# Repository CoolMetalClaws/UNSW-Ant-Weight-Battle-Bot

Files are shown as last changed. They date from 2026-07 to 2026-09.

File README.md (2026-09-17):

# UNSW-Ant-Weight-Battle-Bot



This Project features a 150g Antweight battle Battle bot designed for a competition with a vertical 20,000 RPM spinner weapon. Haven't heard of combat robotics before? It's basically custom RC cars with weapons trying to destroy each other! This bot is my first Antweight bot ever! It features an agressive design with angular features, a powerful vertical rotary weapon, and wide front prongs to guide oponents to the pit! A melenki nano is used as the main control board with N20 motors as the main drive motors, and a BE1806 BLDC is the main weapon motor.

## Parts
### - Chassis
The main chassis of the bot with mounts for motors, the malenki nano, the ESC, the battery, and wiring.

### - Left and Right wheel Spike
Two spikes attached to the drive axels of both wheels, keeping the bot from getting stuck on the side and looking cool! They rotate along with the wheels.

### - Chassis Cover 
A lid for the bot to keep its guts inside when its getting beaten up and keep the LiPo from going boom

### - Front Floor Bumpers
To allow as much contact as possible with the floor when the bot is tilted slightly forwards. Printed separately to avoid supports and to make it easier to replace.

### - Weapon Struts
Previously a part of the chassis, the struts were seperated for easier assembly, easier replacement, and quicker prototyping. Another reason was to increase strength along the layer lines by printing the part flat.

### - Weapon Blade
A drum style asymetrical vertical weapon that has 2 teeth and a nasty bite

## Wiring Diagram



## BOM (Bill Of Materials)

| Component | Cost | Qty | Link |
|---|---|-----|---|
| Malenki Nano | $44.99 | 1x  | https://botbitz.com.au/collections/electronic-speed-controls/products/malenki-nano |
| | | | |
| Blue PETG CF | $22.99 | 1x  | https://siddament.com.au/collections/cf-wood-marble-petg/products/original-blue-petg-cf |
| | | | |
| 195mAh 2S LiPo Battery | $12 each ($50) | 5x  | https://llamaforge.com/product/195mah_2s_13g_lipo_battery/ |
| | | | |
| 34mm N20 Wheel | $1 each ($6) | 6x  | https://llamaforge.com/product/34mm-n20-wheel-4-6g/ |
| | | | |
| Screw Switch | $8 | 1x  | https://llamaforge.com/product/ant-screw-switch-mini-0-5g/ |
| | | | |
| BE1806 1400KV BLDC Motor | $19.80 | 1x  | https://llamaforge.com/product/be1806-motor-1400kv-25g/ |
| | | | |
| BLHELI-S 20A ESC | $15 | 1x  | https://llamaforge.com/product/blheli-s-20a-esc-1-7g/ |
| | | | |
| N20 Motor 1:10 | $8 each ($48)  | 6x  | https://llamaforge.com/product/n20-motor-110-9-7g/ |
| | | | |
| Jumper T16 Controller | $35 | 1x  | Second Hand (Will submit reimbursement report after purchase) |
| | | | |
| M3 Screws Assortment | $12.99 | 1x  | Purchased before to take measurements (Will submit reimbursement report after purchase) |

## Design Onshape Link
https://cad.onshape.com/documents/25a53636e7b7b41d942e0c22/w/8abc8a63af3d41352a374180/e/e18c3659cf4e695e54e4f741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

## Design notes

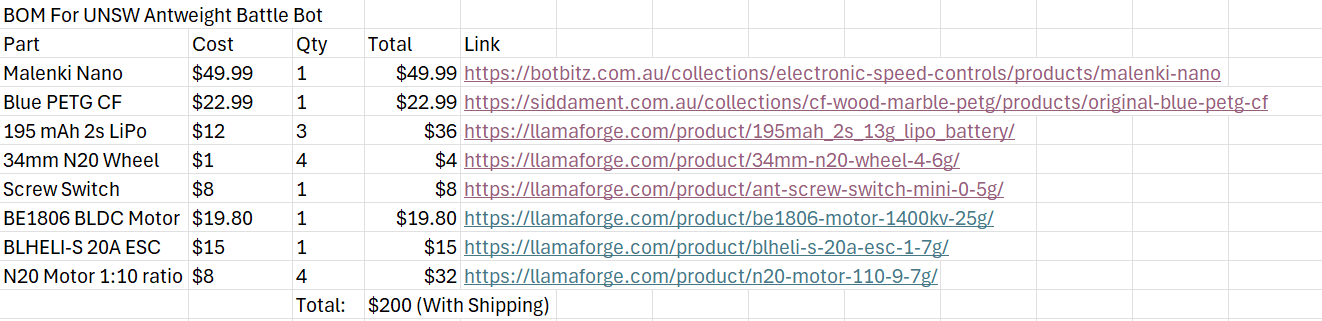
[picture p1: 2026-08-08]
Screenshot 2026-08-08 132551.png

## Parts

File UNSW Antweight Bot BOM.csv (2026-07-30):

BOM For UNSW Antweight Battle Bot
Part | Cost | Qty | Total | Link
Malenki Nano | $49.99 | 1 | $49.99 | https://botbitz.com.au/collections/electronic-speed-controls/products/malenki-nano
Blue PETG CF | $22.99 | 1 | $22.99 | https://siddament.com.au/collections/cf-wood-marble-petg/products/original-blue-petg-cf
195 mAh 2s LiPo | $12 | 3 | $36 | https://llamaforge.com/product/195mah_2s_13g_lipo_battery/
34mm N20 Wheel | $1 | 4 | $4 | https://llamaforge.com/product/34mm-n20-wheel-4-6g/
Screw Switch | $8 | 1 | $8 | https://llamaforge.com/product/ant-screw-switch-mini-0-5g/
BE1806 BLDC Motor | $19.80 | 1 | $19.80 | https://llamaforge.com/product/be1806-motor-1400kv-25g/
BLHELI-S 20A ESC | $15 | 1 | $15 | https://llamaforge.com/product/blheli-s-20a-esc-1-7g/
N20 Motor 1:10 ratio | $8 | 4 | $32 | https://llamaforge.com/product/n20-motor-110-9-7g/
 |  | Total: | $200 (With Shipping)

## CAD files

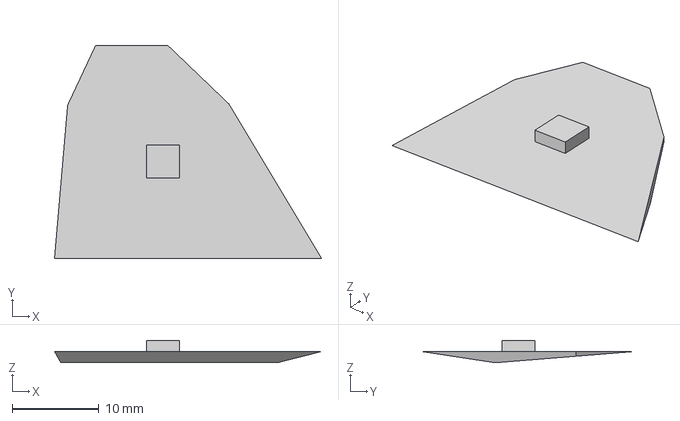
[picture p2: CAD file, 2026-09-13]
Cat-Aclysm MK3 - Chassis Front Floor Bumper Left.step
30.8 x 24.6 x 2.59 mm

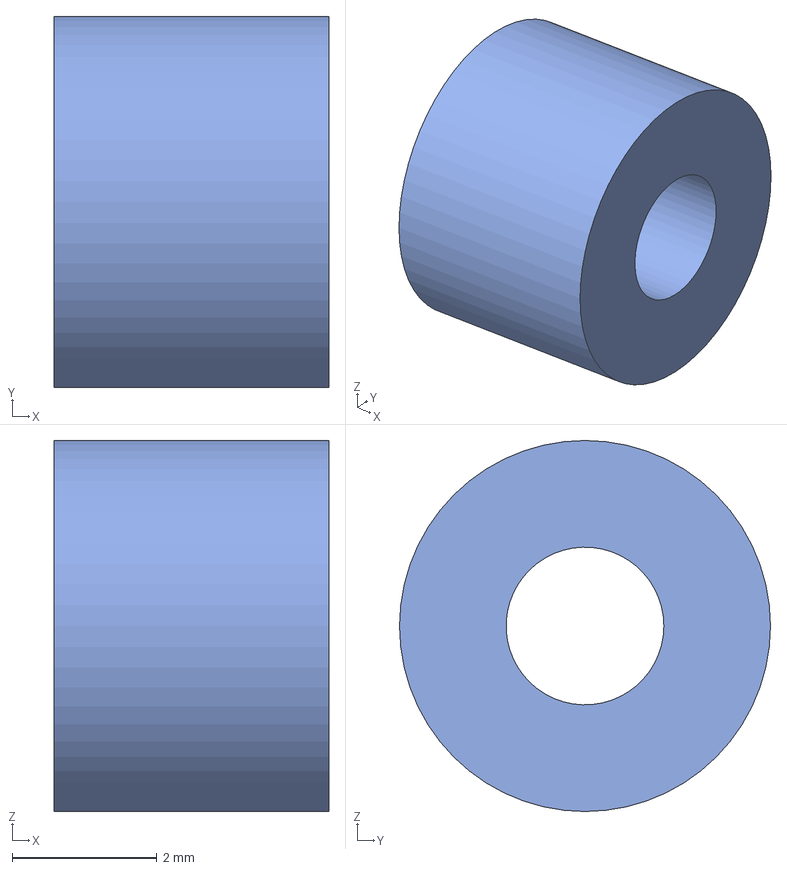
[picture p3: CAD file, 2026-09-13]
Cat-Aclysm MK3 - Bearing and Motor Spacer.step
3.80 x 5.13 x 5.13 mm

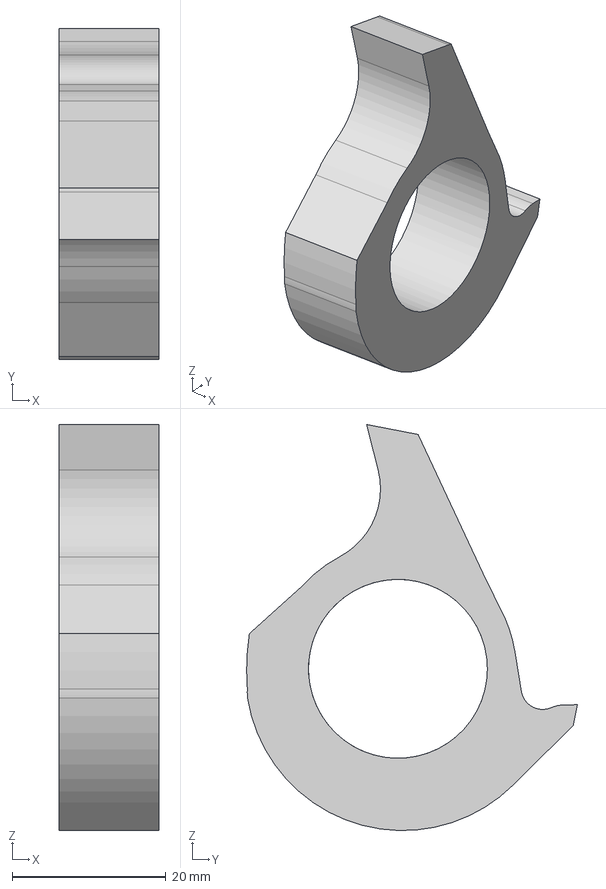
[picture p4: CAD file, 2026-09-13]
Cat-Aclysm MK3 - D.E.S Style Blade MK2 (Mineee).step
13.0 x 43.1 x 52.9 mm

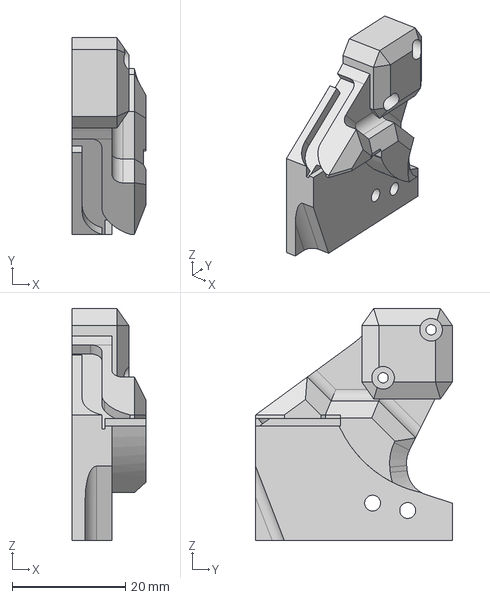
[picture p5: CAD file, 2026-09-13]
Cat-Aclysm MK3 - Left Weapon Strut.step
13.0 x 34.8 x 41.0 mm

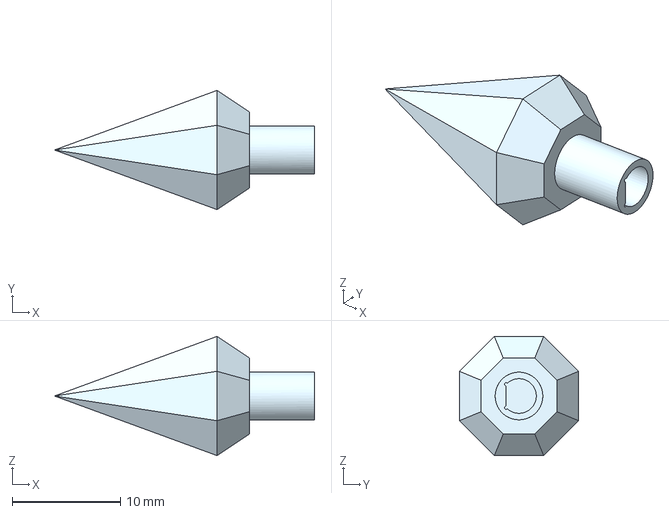
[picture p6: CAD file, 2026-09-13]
Cat-Aclysm MK3 - Right Wheel Spike.step
24.0 x 11.0 x 11.0 mm

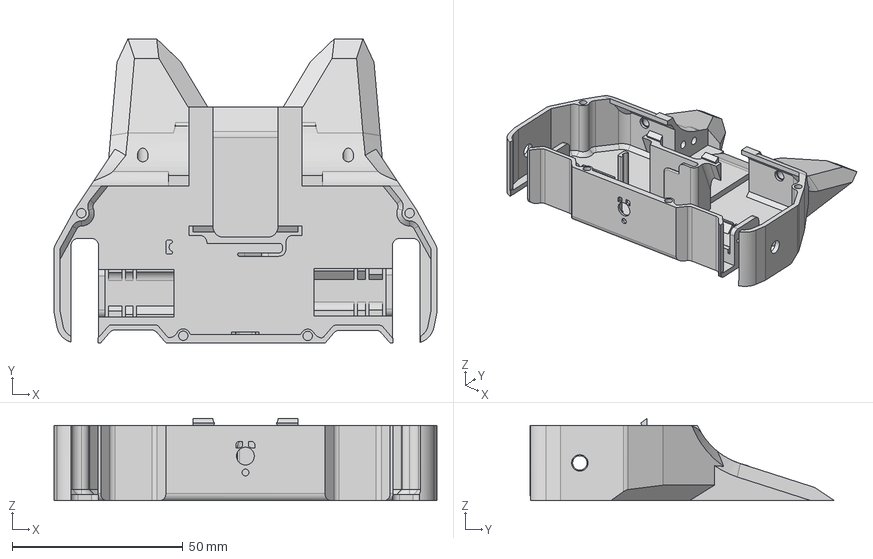
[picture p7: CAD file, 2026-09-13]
Cat-Aclysm MK3 - Chassis (Without Spikes).step
112.0 x 89.0 x 24.0 mm

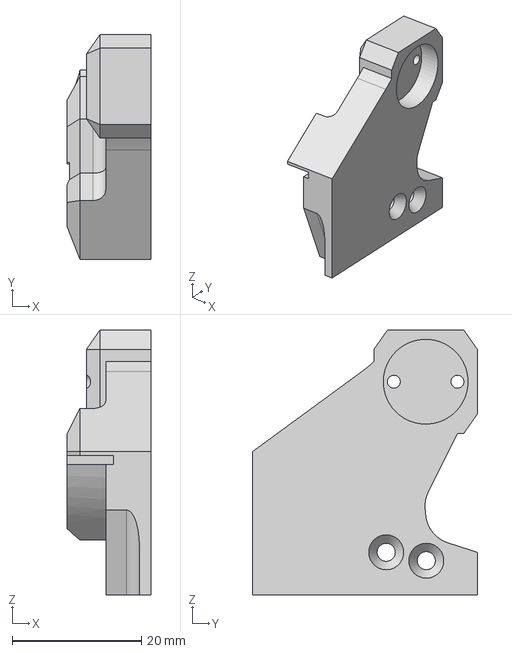
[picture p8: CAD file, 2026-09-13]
Cat-Aclysm MK3 - Right Weapon Strut.step
13.0 x 34.8 x 41.0 mm

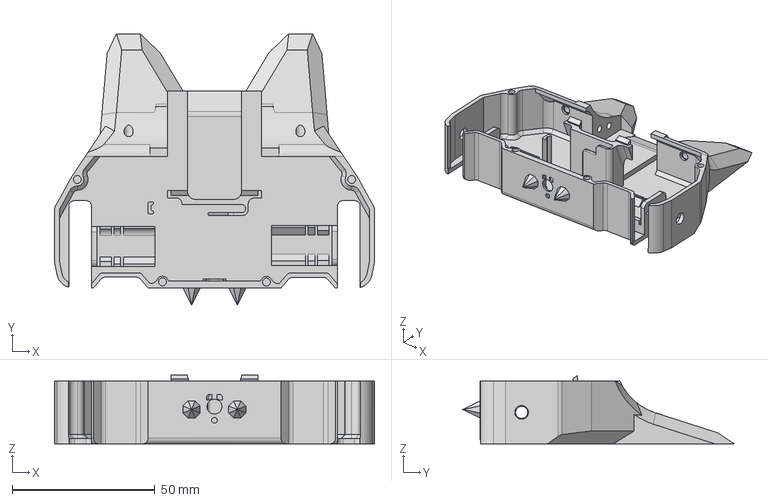
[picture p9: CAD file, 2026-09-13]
Cat-Aclysm MK3 - Chassis With Spikes.step
112.0 x 95.0 x 24.0 mm

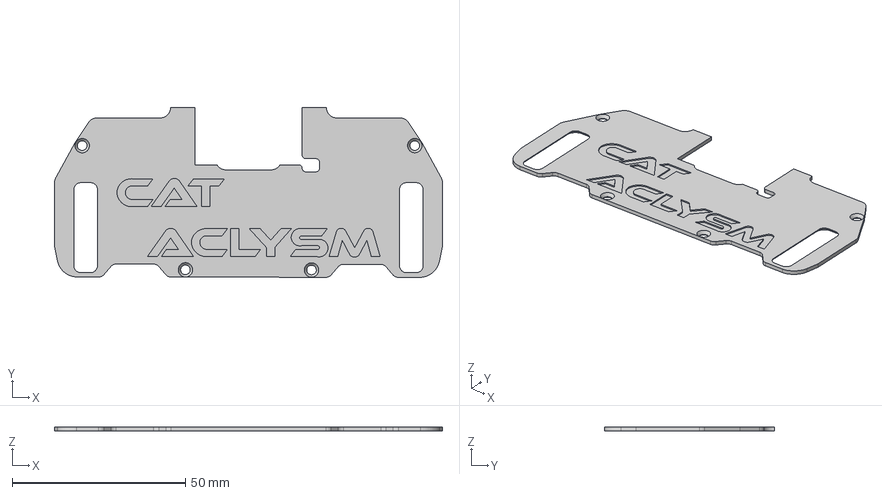
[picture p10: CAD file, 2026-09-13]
Cat-Aclysm MK3 - Chassis Cover.step
112.0 x 49.0 x 1.20 mm

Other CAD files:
Cat-Aclysm MK3 - Left Wheel Spike.step
Cat-Aclysm MK3 - Chassis Front Floor Bumper Right.step

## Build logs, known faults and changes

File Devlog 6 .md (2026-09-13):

# Final Tweaks

## Maths is over!
My maths test is finally done, so now i have some extra time to work on this! Sorry i havent posted a devlog in a while.

## 4hrs of tweaks
Im logging 4hrs of tweaking the design, making tiny changes to make it ready for printing with ABS! Some of the things i changed were;
 - Different type of N20 motor mounts
 - Added weapon motor mounts
 - Made the weapon struts removable and replaceable
 - Added routing for the weapon motor's wires
 - Added screw holes 

## DECIDED UPON A NAME!!!
This bot is officially registered into the competetion in 2 weeks as... drumroll.....Cat Aclysm! This name was chosen since the bot looks kinda like a cat from the top profile.

## Soldering
I began to solder together the parts of the bot, involving very intricate wire splicing because i thought it would be fun to add 2 LEDs instead of the required 1. :/ 

## Thats It!
Thats it for this devlog! Thank you for reading if you made it this far! 



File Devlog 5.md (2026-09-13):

# Partss!

## Funding Approved
Thank you soo much @RR for approving funding for my project! Sorry I haven’t posted a devlog in a while, I was ordering parts and doing the final tweaks to the design. All the parts have been ordered, and I’m currently waiting for delivery.

## Lower Chassis
I lowered the chassis by making the wheels closer to the floor, and sloped the front armour to restrict my bot from getting picked up from the front or outmanoeuvred. This also allows my bot to scoop up other bots and guide them into my weapon blade.

## Mouting the BE1806 motor
I split the chassis struts into seperate parts so they can be printed flat, which makes them stronger vertically. Then I added mounting holes for M2 screws, which directly screw into the motor. Then a channel was extruded to route the motor wires back through the chassis and to the ESC and the Malenki.

## Break
This project will be taking a back seat for the next week as I wait for parts to deliver and due to upcoming exams! I’ll finish the build pretty soon after though, as the event I’m competing in is on 20th September!

## Controller
I also purchased the controller for the bot, and will need to set it up myself soon! It is a Jumper T16 with replaced ribbons. An annoying thing is that i have to charge the batteries using a specific LiPo charger that I don’t have, so I’ll need to get that.

## Thank you!
Thanks for reading this devlog if u made it this far! Hope you’re as excited for this bot as I am! 

## P.S: I still need a name, so please suggest me some names in the comments below! Thank you!



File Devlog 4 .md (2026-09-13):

# Problems have arisen

## Switch Cover design

While I was waiting for the project to get approved for funding, I decided to add a small cover for the screw switch, and generally touch up the design. I countersunk the screw holes for M3 screws I bought (hopefully I can get re-imbursed for these as well) and designed 2 types of covers for the screw switch on the robot that turns it on. The two designs are attached in the image below, so please tell me which one I should keep on the bot! (Spikes or the flat, boring, plain cover)

## Weight Issues

My bot is slightly overweight, around 5 grams over, and I need to drop dead weight, especially from the chassis. I tried hollowing out the front prongs, but this actually increased the weight as it added more walls, meaning a denser design. I then adjusted some slicer settings and thinned the walls of my bot, which got the weight back under the limit. Unfortunately, I would prefer to have some margin as I still need to add hot glue to stick in the motors and the PCB, and my bot is currently 149.8 grams (the limit is 150g).

To solve this issue, I plan to make the blade thinner, which does mean it will have a lesser reach. If anyone has better suggestions to drop weight, pls let me know in the comments since I really would prefer to keep a wider blade.





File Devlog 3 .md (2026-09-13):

## Just a lil extra thing i was working on that i wanted to share!

Below is the image for my robot team's (just me so far) logo; Robo Sapiens! Lol I found this so amusing I had to make a devlog about it!



P.s if anyone has name suggestions for my bot, pls tell me, i currently have no idea what in going to name it

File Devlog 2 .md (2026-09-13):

## Chosen Design
After careful consideration, I chose the aggressive vertical front spinner as my final design. I have moderate to extensive experience in Onshape, so i used that to begin designing. Before beginning to design, i found STEP files for N20 motors and used the dimensions from my planning stage to place in the electronic components. Then i began with a roughly shaped sketch of the design, which i extruded to the desired length. Then I shelled it out with a 2mm wall to allow space for the electronics.



## Weapon design
My weapon blade design is based off James KIrby's D.E.S blade. The weapon support struts are extremely thick as many bots have lost their weapons due to broken struts. The weapon uses a BE1806 motor and a 20Ah ESC to drive it. The weapon unfortunately was not big enough to house the motor, so adjustments had to be made to allow a larger weapon.



## Feedback and Re-iteration
An extremely helpful individual from the university provided me extensive feedback upon the design, which significantly improved my design and allowed my robot to remain under the weight category. Thank you! 

### Specific Design modifications through feedback;
- Changed Malenki nano orientation to vertical just behind weapon
- Allowed the wheels to protrude slighly from the back so the bot doesnt get stuck on its back
- Smaller chassis for lesser weight (Removed unecessary space)
- Added Mounts for screw switch and LED

If you made it this far, thank you for reading! If you have any suggestions for my bot, I’m always willing to improve, so please tell me in the comments below. Thanks!

## Final Design is attached below along with a wiring diagram (It should be unless theres something else to fix)

### P.s there's a cover on the bot, i just dont have it visible in the renders







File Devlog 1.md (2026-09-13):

# Sketching Robot Designs and Parts with Dimensions 

## Inspiration 



I’ve always been intrigued by battle robots, and when I discovered that there is a competition near by that hosts mini battle bots, I was immediately drawn to it. I did lots of research into it and discovered there were many categories and classes. I decided to make a bot for the Antweight plastic class category, and one that would easily be upgraded to the open class category. An example battle bot is shown below (not mine).

## Overview

The Antweight Battle Bot competition is a miniature combat robotics event where custom-built remote-controlled machines face off in a bulletproof, enclosed arena. This weight class serves as the ultimate entry point for engineering hobbyists due to its low cost, minimal space requirements, and strict design constraints.

## Weapon and drive motor sketches with dimensions

I first sketched out the motors and electronic components used for the battle bot at a 1:1 scale with dimensions, to give me a better sense of the sizing of the parts and to start thinking of the arrangements.

## Bot concept sketches 

After planning a base robot in my mind, I finalised 3 main robot designs I liked. I sketched these 3 out and asked for input from a few people who have experience in this field, including Angus from makers muse (the YouTuber). I decided upon the vertical spinner design with aggressive front forks. My 3 bot sketches are attached below.

### Version 1: Viper


### Version 2: (Unamed)


### Version 3: Skull Krusher


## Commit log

2026-07-30 Enhance README with project details and BOM
    Added detailed parts list, wiring diagram, and BOM to README.
2026-07-30 Added BOM in .csv format
    [UNSW Antweight Bot BOM.csv]
2026-08-08 Enhance BOM section with links and images
    Updated BOM with product links and images.
2026-08-08 Revise BOM with new product details and images
    Updated BOM section with product links and images.
2026-08-08 BOM Screenshot
2026-08-11 Delete UNSW Antweight Battle Bot With Protruding back wheels - Chassis V2 STEP.step
    I need to upload new files (V3)
    [UNSW Antweight Battle Bot With Protruding back wheels - Chassis V2 STEP.step]
2026-08-11 Delete UNSW Antweight Battle Bot With Protruding back wheels - Chassis V2.stl
    I need to upload new V3 files
    [UNSW Antweight Battle Bot With Protruding back wheels - Chassis V2.stl]
2026-08-11 Delete UNSW Antweight Battle Bot With Protruding back wheels - Left Wheel Spike STEP.step
    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
    [UNSW Antweight Battle Bot With Protruding back wheels - Left Wheel Spike STEP.step]
2026-08-11 Delete UNSW Antweight Battle Bot With Protruding back wheels - Left Wheel Spike.stl
    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
    [UNSW Antweight Battle Bot With Protruding back wheels - Left Wheel Spike.stl]
2026-08-11 Delete UNSW Antweight Battle Bot With Protruding back wheels - Right Wheel Spike STEP.step
    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
    [UNSW Antweight Battle Bot With Protruding back wheels - Right Wheel Spike STEP.step]
2026-08-11 Delete UNSW Antweight Battle Bot With Protruding back wheels - Right Wheel Spike.stl
    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
    [UNSW Antweight Battle Bot With Protruding back wheels - Right Wheel Spike.stl]
2026-08-20 Refactor BOM section to table format
    Updated BOM section to use a table format for better readability and removed old list format.
2026-08-20 Enhance README with new components descriptions
    Added sections for Chassis Cover and Weapon Blade to the README.
2026-08-21 Add Jumper T16 Controller to BOM
    Added Jumper T16 Controller entry with pricing and notes.
2026-08-21 Change Malenki Nano cost from $49.99 to $44.99
    Updated the cost of Malenki Nano in the BOM section as it has been put on at a reduced price
2026-09-13 Add Devlog 5 with project updates and plans
    Documented recent project updates including funding approval, chassis modifications, motor mounting, and upcoming plans.
2026-09-13 Update Devlog 6 with recent progress and changes
    Added details about recent design tweaks, bot name, and soldering progress.
2026-09-13 Delete UNSW Antweight Battle Bot With Protruding back wheels MK2 - Chassis Cover.step
    Need to update files
    [UNSW Antweight Battle Bot With Protruding back wheels MK2 - Chassis Cover.step]
2026-09-13 Delete UNSW Antweight Battle Bot With Protruding back wheels MK2 - Chassis.step
    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
    [UNSW Antweight Battle Bot With Protruding back wheels MK2 - Chassis.step]
2026-09-13 Delete UNSW Antweight Battle Bot With Protruding back wheels MK2 - D.E.S Style Blade MK2 (Mineee) (1).step
    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
    [UNSW Antweight Battle Bot With Protruding back wheels MK2 - D.E.S Style Blade MK2 (Mineee) (1).step]
2026-09-13 Delete UNSW Antweight Battle Bot With Protruding back wheels MK2 - Left Wheel Spike.step
    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
    [UNSW Antweight Battle Bot With Protruding back wheels MK2 - Left Wheel Spike.step]
2026-09-13 Delete UNSW Antweight Battle Bot With Protruding back wheels MK2 - Right Wheel Spike.step
    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
    [UNSW Antweight Battle Bot With Protruding back wheels MK2 - Right Wheel Spike.step]
2026-09-13 Add the final STEP files
    Add the final STEP files for the combat robot, CAT ACLYSM!
    [Cat-Aclysm MK3 - Chassis Cover.step, Cat-Aclysm MK3 - Bearing and Motor Spacer.step, Cat-Aclysm MK3 - Chassis (Without Spikes).step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]
